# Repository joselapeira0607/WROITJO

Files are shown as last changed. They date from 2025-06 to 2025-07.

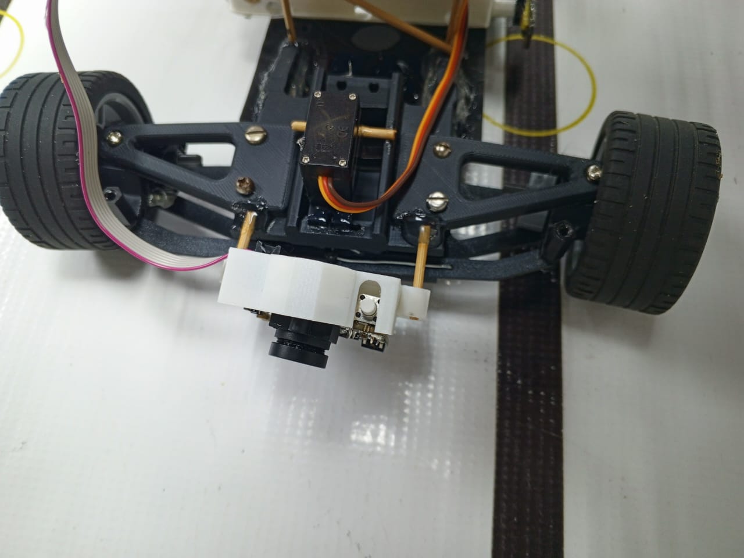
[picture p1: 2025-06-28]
v-photos/pixy-view.jpeg

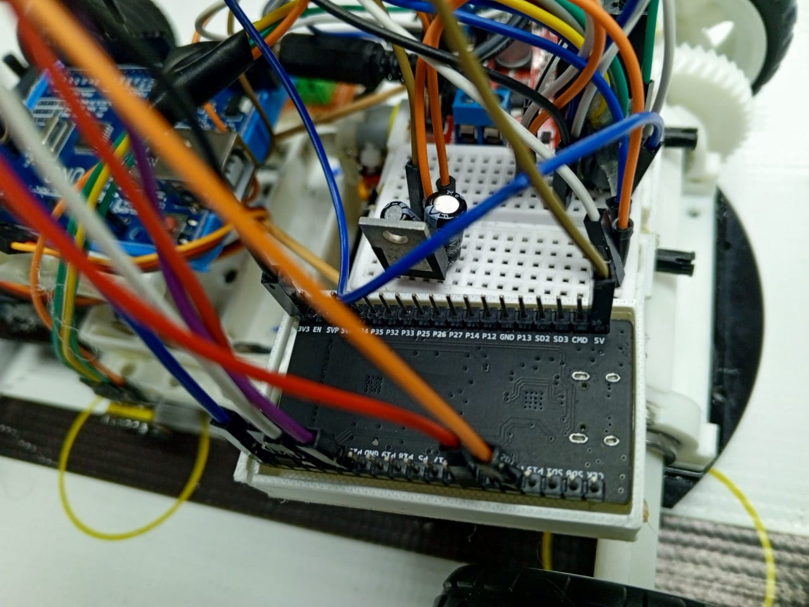
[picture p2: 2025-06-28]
v-photos/esp32-view.jpeg

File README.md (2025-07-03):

<h1 align="center"> Autonomous Robot Project for WRO - Future Engineers Category </h1>

<p align="center"> banner </p>

<br>
<h1 align="center"> World Robot Olympiad </h1>


<br>

The World Robot Olympiad (WRO) is a prestigious international robotics competition that stimulates the imagination of students worldwide. It challenges participants to demonstrate their creativity, problem-solving skills, and technical expertise in designing and programming robots for various tasks and challenges.

One of the most dynamic categories in WRO is Future Engineers. In this category, participants are tasked with developing innovative solutions to real-world problems using robotics and automation. This category serves as a breeding ground for future innovators, encouraging critical and creative thinking among students, laying the foundation for a new generation of engineers and technologists.

This year, the Future Engineers category presents an exciting challenge: creating an autonomous car. This challenge pushes participants to explore cutting-edge robotics, adding complexity and innovation to an already thrilling competition.

# 📁 Repository Structure

| Directory | Type | Description | Required |
|---|---|---|---|
| **/t-photos**  | 📸 Photos | - 1 official team photo (`team_official.jpg`)<br>- 1 informal group photo (`team_fun.jpg`) | ✅ Required |
| **/v-photos**  | 🖼️ Photos  | - 6 technical views of the robot (front, side, rear, top, bottom, detail)<br>- Minimum resolution: 1920x1080<br>- Format: `robot_[angle].jpg` | ✅ Required |
| **/video** | 🎥 Multimedia | `video.md` file containing:<br>- YouTube link (public/unlisted)<br>- Minimum 30-second demonstration<br>- Must show autonomous navigation | ✅ Required |
| **/schemes** | 📐 Diagrams | Diagrams in JPEG/PNG/PDF of:<br>- Electronic schematic<br>- Wiring connections<br>- Mechanical layout | ✅ Required |
| **/src** | 💻 Code  | Recommended structure:<br>- `/firmware` (Arduino/ESP32 code)<br>- `/vision` (image processing)<br>- `/docs` (technical manuals) | ✅ Required |
| **/models** | 🖨️ 3D/CNC | Optional files:<br>- Formats: STL, DXF, STEP<br>- Organized by component | ❌ Optional |
| **/other** | 📄 Extra | Additional documentation:<br>- Communication protocols<br>- Technical Report<br> | ❌ Optional |

## Project Objective
The objective of this project is to design, build, and program an autonomous robot using open-source hardware, sensor-based decision making, and adaptive movement algorithms. Our robot dynamically analyzes its environment through integrated processing and sensor feedback, ensuring efficient navigation while autonomously overcoming obstacles.

Main objectives:
* Strengthen problem-solving and teamwork in real-world engineering
* Implement sensor-based motion control for precise navigation
* Develop an optimized autonomous driving strategy for robotics challenges
* Contribute to open-source robotics by documenting our solution for future teams

## Components Used

Our robot is built with precision hardware to ensure stability, responsiveness, and energy optimization.

<table>
  <tr>
    <th width="150">Component</th>
    <th>Image</th>
    <th>Technical Description</th>
  </tr>
  
  <tr>
    <td><strong>Arduino Uno</strong></td>
    <td>Arduino Uno</td>
    <td>Main microcontroller managing sensor input (I2C, digital) and motion control (PWM).<br>
    <em>Specifications:</em> ATmega328P, 16MHz, 32KB flash, 14 digital I/O</td>
  </tr>

  <tr>
    <td><strong>L298N H-Bridge</strong></td>
    <td>L298N H-Bridge</td>
    <td>Dual-channel motor controller for direction and speed.<br>
    <em>Specifications:</em><br>
    • Logic voltage: 5V<br>
    • Motor voltage: +5V to +35V<br>
    • Peak current: 2A per channel<br>
    • Maximum power: 25W<br>
    • Protection: Built-in suppression diodes<br>
    <em>Arduino connection:</em><br>
    • ENA/ENB → PWM pins (speed)<br>
    • IN1/IN2 → Digital pins (direction)<br>
    • +12V → External 9V source<br>
    <em>Project use:</em> Bidirectional control of NXT motor</td>
  </tr>

<tr>
  <td><strong>DC Motor with Gearbox</strong></td>
  <td>DC Motor</td>
  <td>Compact brushed DC motor with built-in gear reduction system.<br>
  <em>Specifications:</em><br>
  • Voltage: 6–12V DC<br>
  • Gear ratio: varies by model (e.g., 48:1)<br>
  • Shaft: 6mm D-type<br>
  • Torque and speed optimized for robotic applications<br>
  <em>Wiring:</em> Two terminal leads (red: +, black: -) for connection to an L298N driver or similar H-bridge controller</td>
</tr>
  
  <tr>
    <td><strong>ESP32-WROOM-32D</strong></td>
    <td>ESP32-WROOM-32D</td>
    <td>Wi-Fi/Bluetooth MCU for IoT and embedded systems.<br>
    <em>Capabilities:</em> Dual-core 240MHz, 4MB Flash, 520KB SRAM, 802.11 b/g/n Wi-Fi, Bluetooth 4.2, low-power modes.</td>
  </tr>

  <tr>
    <td><strong>VL53L0X Sensors</strong></td>
    <td>VL53L0X</td>
    <td>Time-of-Flight (ToF) sensor for obstacle detection.<br>
    <em>Range:</em> 50-1200mm, ±3% accuracy, I2C interface</td>
  </tr>

  <tr>
    <td><strong>Breadboard</strong></td>
    <td>Breadboard</td>
    <td>Prototyping platform for quick interconnections.<br>
    <em>Configuration:</em> 830 points, power bus distribution</td>
  </tr>

  <tr>
    <td><strong>Voltage Regulators</strong></td>
    <td>LM7805 Regulator</td>
    <td>Power management system.<br>
    <em>Specifications:</em> LM7805 (5V, 1A), LM1117 (3.3V), with heat sinks</td>
  </tr>

  <tr>
    <td><strong>SG90 Servomotor</strong></td>
    <td>SG90 Servo</td>
    <td>Direction control and auxiliary mechanisms.<br>
    <em>Specifications:</em> 4.8-6V, 180° rotation, 1.8kg/cm torque</td>
  </tr>

<tr>
  <td><strong>HC-SR04 Ultrasonic Sensor</strong></td>
  <td>HC-SR04 Ultrasonic Sensor</td>
  <td>Non-contact distance measurement using ultrasonic waves.<br>
  <em>Specifications:</em> 
  <ul>
    <li>Measuring range: 2cm - 400cm</li>
    <li>Accuracy: ±3mm</li>
    <li>Operating voltage: 5V DC</li>
    <li>Current consumption: 15mA</li>
    <li>Frequency: 40kHz</li>
    <li>Detection angle: 15°</li>
  </ul>
  ESP32 connection: Trig (GPIO), Echo (GPIO), VCC (5V), GND</td>
</tr>

  <tr>
    <td><strong>Pixy2 Camera</strong></td>
    <td>Pixy2 Camera</td>
    <td>Embedded vision system for color-based object detection.<br>
    <em>Specifications:</em><br>
    • Dual-core NXP LPC4330 processor (200MHz)<br>
    • Resolution: 1296x976 (RAW), 316x208 (processed)<br>
    • Color signatures: 7 simultaneous detections<br>
    • Interfaces: SPI, I2C, UART, USB<br>
    • Power consumption: 140mA @ 5V<br>
    <em>Connection:</em> SPI (recommended) + 5V power supply<br>
    <em>Project use:</em> Target detection through color codes (signatures 3 & 4)</td>
  </tr>
</table>

## Sensor Processing and Autonomous Navigation
The VL53L0X sensor plays a crucial role in obstacle detection, allowing the robot to measure distance in real time and adjust its movement accordingly. The robot follows a sensor-driven motion algorithm, continuously refining motor speed and navigation logic.

* Obstacle detection: The distance sensor identifies objects and dynamically adjusts the robot's path
* ESP32 camera input: Processes real-time images for terrain analysis and movement decisions
* Motor control logic: The Arduino Uno manages speed control through PWM signals and servo adjustments

## Required Software and Development Tools
Programming and compilation tools:
* Arduino IDE - Used for coding, compiling and uploading firmware
* Tinkercad - Virtual electronics simulation tool for circuit prototyping

Essential libraries:
* Wire.h - Supports sensor communication and data collection
* Adafruit_VL53L0X.h - Controls distance measurement operations
* Servo.h - Manages servo motor positioning and feedback control

## Installation and Operation Instructions
How to deploy the robot firmware:
1. Download Arduino IDE and install all necessary board drivers
2. Connect Arduino Uno via USB and verify IDE recognition
3. Install all required libraries (VL53L0X, Servo, Wire, Adafruit Motor Control)
4. Compile and upload firmware, initializing sensor motion algorithms
5. Test sensor performance using Serial Monitor readings
6. Run autonomous navigation tests and fine-tune movement responses

## Diagnostics and Evaluation
Performance validation tests:
* Sensor accuracy test: Confirms obstacle detection reliability and distance precision
* Motor speed calibration: Ensures smooth motion transitions and speed adjustments
* Servo alignment: Evaluates response time and angle precision for additional motion control
* Camera-based navigation: Assesses terrain recognition and edge detection capabilities

## Competitive Strategy and Adaptability
Our robot is designed to react dynamically in competition environments, ensuring maximum precision and adaptability:

* Real-time sensor data: The robot instantly adjusts movement based on incoming distance measurements
* Vision-based edge detection: The ESP32 processes camera input to determine safe paths and avoid barriers
* Energy-efficient motion management: Reduces unnecessary movement to optimize navigation cycles
* Configurable control logic: Adjusts servo responsiveness and motor calibration as needed

## Future Development and Contribution
Our long-term vision for the project includes:

* Expanding servo control capabilities for more precise motion adjustments
* Optimizing ESP32 vision-based object tracking for advanced competition scenarios
* Developing smart battery management strategies to improve longevity and operational efficiency
* Publishing open-source documentation on sensor-based autonomous navigation solutions

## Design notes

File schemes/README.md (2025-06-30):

<h1 align="center">Schematic diagrams</h1>

Diagrama en blanco (1)

# 📁 Bill of materials

| Quantity | Component | Image | Description |
|---|---|---|---|
| 1 | Arduino Uno | Arduino | Open-source microcontroller board for prototyping. |
| 1 | Breadboard | Breadboard | Reusable platform for temporary circuits. |
| 1 | H-Bridge (L298N) | H-Bridge | Motor driver to control DC motors direction/speed. |
| 1 | DC Motor with Gearbox | DC Motor with gearbox | DC motor with a gear reduction system, ideal for increasing torque and reducing output speed. |
| 1 | Servo (S090) | Servo | Compact servo motor (0°-180° rotation). |
| 2 | VL53L0X | VL53L0X | Time-of-Flight (ToF) laser distance sensor. |
| 1 | ESP32-WROOM-32D  | ESP32 | Dual-core Wi-Fi/Bluetooth MCU for IoT. |
| 1 | Pixy2  |  | Programmable camera sensor that detects objects by color (up to 7 signatures simultaneously). Ideal for line tracking, object detection, and autonomous robot navigation. |
| 1 | HC-SR04 Ultrasonic Sensor | HC-SR04 | Affordable distance sensor that uses ultrasonic waves to detect obstacles at medium to long range. Ideal for front-facing obstacle detection. |

## ✅ Justification of Component Selection

Each component was selected based on its ability to address specific technical needs of the WRO circuit, ensuring reliable operation, integration, and performance in real-time autonomous navigation.

### 🧠 Arduino Uno
Used in the prototyping phase as a versatile and accessible microcontroller that allowed basic interfacing with sensors, actuators, and debugging tasks. It served as the foundation for early system validation before migrating to a more powerful processing unit.

### 🔌 Breadboard
Employed to expand the number of power and ground distribution points without soldering, the breadboard simplified prototyping and allowed flexible rearrangement of components across multiple testing stages.

### 🔀 L298N H-Bridge
The L298N module was critical for controlling the direction and speed of the DC motor via PWM signals. Its dual output channels made it ideal for simultaneously managing both propulsion and peripheral motion with sufficient current tolerance.

### ⚙️ DC Motor with Gearbox
Chosen for its ability to move the robot efficiently, this motor's built-in reduction gear translated high-speed rotation into greater torque, providing stability and acceleration — essential for covering the competition track rapidly and reliably.

### ↪️ SG90 Servo Motor
Responsible for adjusting the vehicle's heading, this servo was directly linked to the obstacle avoidance system. Based on input from lateral sensors and visual cues, the servo altered the front wheel angle to enable real-time evasive maneuvers.

### 👁️ VL53L0X Sensors
These Time-of-Flight sensors measured lateral distances to nearby walls or barriers. Their data fed into the control logic, triggering servo movements to prevent collisions and maintain central alignment within the circuit.

### 🎥 Pixy2 Camera
Enabled the robot to visually detect critical elements of the course such as colored columns or stoplights. It interpreted multiple color signatures in real time and passed this information to the control algorithm, allowing dynamic decisions such as obstacle avoidance or behavior modulation based on color context.

### 📡 HC-SR04
The HC-SR04 was integrated into the robotic platform as a forward-facing obstacle detection module. Its working principle—based on the reflection of ultrasonic sound waves—allowed the system to calculate the distance to frontal objects accurately within a 2–400 cm range. This made it especially useful for early detection of walls or barriers directly ahead of the robot.

### 🧠 ESP32-WROOM-32D
Deployed as the final microcontroller for its high processing speed, dual-core architecture, and robust I2C handling. It coordinated simultaneous tasks: managing sensors, computing navigation logic, and driving actuators — all essential for WRO's fast-paced circuit environment.

---

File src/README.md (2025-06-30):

# Autonomous Vehicle Control System

An Arduino-based control system for autonomous navigation using distance sensors and servo steering.

Diagrama en blanco

### Parameters
```cpp
#include <Servo.h>  // Include the Servo library to control the steering mechanism

// === PIN CONFIGURATION ===
const int motorPin1 = 3;  // Pin to control motor direction (forward)
const int motorPin2 = 6;  // Pin to control motor direction (reverse or stop)
const int servoPin   = 9; // PWM pin connected to the servo motor for steering

// === SERVO STEERING LIMITS ===
const int ANGLE_CENTER       = 90;  // Neutral angle: wheels aligned straight
const int ANGLE_MAX_RIGHT    = 120; // Max turn right angle
const int ANGLE_MAX_LEFT     = 60;  // Max turn left angle

// === SENSOR LOGIC AND SAFETY LIMITS ===
const int DIFFERENCE_THRESHOLD = 30;    // Acceptable difference (in mm) between sensors to consider straight
const int MAX_DIFFERENCE       = 160;   // Max expected measurable difference to scale the steering
const int SENSOR_TIMEOUT       = 1000;  // Stop the vehicle if no sensor data is received within this time (in ms)

// === LAPS AND TURNS CONTROL ===
const int TURNS_PER_LAP = 4;  // Number of turns that count as one lap
const int MAX_LAPS      = 3;  // Stop the vehicle after completing this many laps

// === GLOBAL VARIABLES ===
Servo myServo;                   // Servo object to control steering
String receivedData = "";        // Buffer to collect incoming serial data
bool newData         = false;    // Flag indicating whether a complete command was received
int sensorValue1     = 0;        // Latest reading from sensor 1
int sensorValue2     = 0;        // Latest reading from sensor 2
unsigned long lastSensorUpdate = 0; // Timestamp of last sensor input

// === STATE OF THE VEHICLE ===
int turnsDetected     = 0;       // Counts how many turns have been completed in the current lap
int lapsCompleted     = 0;       // Total laps completed
bool isTurning        = false;   // Tracks if the robot was turning in the last cycle
bool vehicleStopped   = false;   // True when the robot finishes its mission or hits a timeout

void setup() {
  Serial.begin(9600);  // Start serial communication to receive sensor data
  Serial.println("Arduino: System started. Waiting for sensor data...");

  pinMode(motorPin1, OUTPUT); // Motor direction pin 1
  pinMode(motorPin2, OUTPUT); // Motor direction pin 2

  myServo.attach(servoPin);   // Attach servo control to the designated pin
  centerServo();              // Initialize with centered steering
}

// === MOVEMENT CONTROL FUNCTIONS ===
void moveForward() {
  // Set motor to move forward
  digitalWrite(motorPin1, HIGH);
  digitalWrite(motorPin2, LOW);
}

void stopVehicle() {
  // Stop the motor and straighten steering
  digitalWrite(motorPin1, LOW);
  digitalWrite(motorPin2, LOW);
  centerServo();
  Serial.println("Movement: Stopped");
}

// === SERVO CONTROL ===
void centerServo() {
  // Set servo to center position
  myServo.write(ANGLE_CENTER);
}

void turnRight(int angle) {
  // Clamp angle to max range and turn servo right
  angle = constrain(angle, ANGLE_CENTER, ANGLE_MAX_RIGHT);
  myServo.write(angle);
  Serial.print("Direction: Turning right to ");
  Serial.print(angle);
  Serial.println(" degrees");
}

void turnLeft(int angle) {
  // Clamp angle to max range and turn servo left
  angle = constrain(angle, ANGLE_MAX_LEFT, ANGLE_CENTER);
  myServo.write(angle);
  Serial.print("Direction: Turning left to ");
  Serial.print(angle);
  Serial.println(" degrees");
}

// === SERIAL COMMUNICATION HANDLING ===
void recvSerialData() {
  // Reads incoming characters until newline '\n' is detected
  while (Serial.available() > 0) {
    char receivedChar = Serial.read();
    if (receivedChar == '\n') {
      newData = true; // Full command received
      break;
    }
    receivedData += receivedChar;
  }
}

void processSerialCommand() {
  // Distinguish between Sensor 1 and Sensor 2 data
  if (receivedData.startsWith("S1:")) {
    processSensorData(receivedData, sensorValue1, 1);
  } 
  else if (receivedData.startsWith("S2:")) {
    processSensorData(receivedData, sensorValue2, 2);
  }

  // Reset input buffer after processing
  receivedData = "";
  newData = false;
  lastSensorUpdate = millis();  // Update the timestamp
}

void processSensorData(String &data, int &sensorValue, int sensorNum) {
  // Extract the number from format like "S1: 123 mm"
  int mmIndex = data.indexOf(" mm");
  if (mmIndex != -1) {
    int startIndex = data.indexOf(":") + 2;
    String valueString = data.substring(startIndex, mmIndex);
    sensorValue = valueString.toInt();

    Serial.print("Sensor ");
    Serial.print(sensorNum);
    Serial.print(" updated: ");
    Serial.print(sensorValue);
    Serial.println(" mm");
  }
}

// === NAVIGATION DECISION MAKING ===
void updateSteering() {
  if (vehicleStopped) return; // If vehicle is halted, skip

  int difference = sensorValue1 - sensorValue2;

  if (abs(difference) <= DIFFERENCE_THRESHOLD) {
    // Continue straight if difference is within tolerance
    centerServo();
    handleTurnCompleted();
  } 
  else {
    // Map the difference linearly into an appropriate steering angle
    int servoAngle = map(difference, -MAX_DIFFERENCE, MAX_DIFFERENCE, 
                         ANGLE_MAX_LEFT, ANGLE_MAX_RIGHT);
    servoAngle = constrain(servoAngle, ANGLE_MAX_LEFT, ANGLE_MAX_RIGHT);

    // Turn left or right accordingly
    if (difference > 0) {
      turnRight(servoAngle);
    } else {
      turnLeft(servoAngle);
    }

    isTurning = true; // Flag that we're mid-turn
  }
}

void handleTurnCompleted() {
  // Detect change from turning to straight
  if (isTurning) {
    turnsDetected++;
    Serial.print("Turn completed. Total: ");
    Serial.println(turnsDetected);

    // If number of turns equals one full lap
    if (turnsDetected >= TURNS_PER_LAP) {
      lapsCompleted++;
      Serial.print("Lap completed: ");
      Serial.println(lapsCompleted);

      turnsDetected = 0; // Reset counter for the next lap

      if (lapsCompleted >= MAX_LAPS) {
        // Mission success! Stop everything
        vehicleStopped = true;
        stopVehicle();
        Serial.println("Mission complete: 3 laps finished");
      }
    }

    isTurning = false; // Reset turn state
  }
}

void checkSensorTimeout() {
  // If too much time passed without sensor input, stop for safety
  if (millis() - lastSensorUpdate > SENSOR_TIMEOUT) {
    Serial.println("WARNING: Sensor timeout. Stopping vehicle...");
    stopVehicle();
    vehicleStopped = true;
  }
}

// === MAIN LOOP ===
void loop() {
  if (vehicleStopped) return; // Skip logic if mission is already done

  recvSerialData();       // Check for new sensor data
  if (newData) {
    processSerialCommand();
  }

  // Run only if vehicle is allowed to move
  if (!vehicleStopped) {
    moveForward();        // Activate motors
    updateSteering();     // Adjust direction based on sensors
    checkSensorTimeout(); // Safety mechanism
  }
}

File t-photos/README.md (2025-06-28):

## Who Are We?

We are JO SLD, a dynamic and passionate team proudly born from the classrooms of Jesús Obrero Technical Institute, an institution known for nurturing skilled professionals grounded in discipline, innovation, and teamwork. Our name carries the initials of our members—José, Keiner, and Mauricio—and represents our shared commitment to excellence in robotics and technology.

Our team is made up of:

- José Lapeira – High school graduate in Computer Science. A coding strategist with a keen eye for algorithmic logic and system structure. His precision is reflected in every line of code.

- Keiner Durán – Also a Computer Science graduate, he’s the integration specialist of the team. Always seeking ways to improve performance and synchronization between hardware and software components.

- Mauricio Sánchez – Electronics high school graduate and IT college technician (TSU). The electronics mastermind who balances circuit design with technical robustness and reliability.

At Jesús Obrero, we didn’t just learn theory—we embraced a way of thinking: with purpose, detail, and unity. Our mission is to represent our school, our community, and our country through projects that combine technology, creativity, and social impact.

Our motto: “From technique to impact” — because each prototype we build is our way of contributing to a smarter, better future.

Official:
official

Funny photo:
funny

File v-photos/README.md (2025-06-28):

Vehicle's photos
====

## Front position
front-view

## Left position
right-view

## Right position
left-view

## Back position
back-view

## Top position
top-view

## Bottom position
bottom-view

## Wheels
wheels-view

## Arduino
arduino-view

## Batteries
batteries

## Esp32
esp32-view

## Pixy2
pixy-view

## H Bridge
H bridge-view

## Motor 
motor-view

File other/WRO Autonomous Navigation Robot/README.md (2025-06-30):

<h1 align="center">Technical Report</h1>
<h2 align="center">Development of an Autonomous Robot for the World Robot Olympiad (WRO)</h2>

<p align="center"><i>Complete documentation of the design, optimization, and results of an autonomous mobile robot prepared to navigate obstacle-filled closed circuits.</i></p>

---

## 🧭 Introduction

This document provides a detailed description of the design, assembly, optimization, and validation process of an autonomous robot created to compete in the World Robot Olympiad (WRO). The primary technical objective was to enable the robot to complete three laps within a closed circuit while precisely avoiding walls and intermediate obstacles.

Throughout the process, we addressed challenges in three fundamental areas: mechanics, electronics, and intelligent control. Technical iterations allowed us to refine both the hardware and navigation algorithm, resulting in a robust and reliable system.

> 📷 460205220-4385875f-8fb5-4cfd-8109-ed76797ce5a7

---

## 🧪 Initial Phase: LEGO Prototyping (March)

The initial stage focused on building a functional prototype using LEGO Mindstorms components, given their modular versatility and ease of testing.

### Mechanical Design

We developed a basic chassis with LEGO components, which incorporated:
- A differential steering system
- Front wheels connected to a 3D-printed toothed beam actuated by a servo motor
- Rear wheels with traction provided by an NXT motor

### Electronic Circuit

The initial control and detection system consisted of:
- **Microcontroller:** Arduino UNO  
- **Motor control:** L298N H-bridge  
- **Sensing:** Two HC-SR04 ultrasonic sensors positioned front and side  
- **Power:** Three 4V rechargeable batteries connected in series (12V total) distributed via breadboard  

> 📷 

### Identified Technical Issues

During initial testing, we identified significant limitations:
- High sensitivity to ultrasonic noise in HC-SR04 sensors, causing false detections
- Limited precision in tight turns due to structural flexibility of the LEGO differential system
- Torque loss and vibrations from NXT motor overheating at high speeds

---

## 🔧 Optimization: Sensors and Controller

Based on the identified issues, we restructured the sensing and control system.

### Migration to VL53L0X Sensors

The ultrasonic system was replaced with VL53L0X Time-of-Flight sensors, which offered:
- Millimeter resolution with high stability
- Immunity to environmental acoustic interference
- Adjustable detection range up to 2 meters

**Resulting challenges:**
- Sensor performance was affected by excessive lighting
- I2C protocol readings required higher processing speed

### ESP32 Integration

To improve parallel reading and processing capability, we integrated an ESP32 that provided:
- Dual-core processing for multitasking (parallel sensor reading and motor control)
- More efficient I2C communication without bus congestion

---

## ⚙️ Mechanical Redesign: DKS-Basic Chassis

### LEGO Chassis Limitations
- Low structural rigidity under dynamic loads
- Play in mobile connections
- Excessive weight, reducing agility and autonomy

### DKS-Basic Advantages

We transitioned to a professional metal chassis (DKS-Basic) that offered:
- Greater resistance thanks to anodized aluminum
- Ball bearing system reducing friction
- More compact geometry optimizing tight turns
- Compatibility with commercial DC motors

### Traction System Upgrade
- Replaced NXT motor with gear-reduced DC motor
- Improved torque and speed control with PWM signal
- Custom CAD-designed 3D-printed wheels adapted to the new chassis bearings

> 📷 left-view

---

## 🧠 Final Sensing and Control System

### Sensor Configuration

The final version incorporated a hybrid sensor architecture:
- 1x HC-SR04 (front position) for long-range obstacle detection
- 2x VL53L0X (side) for curve navigation and precise avoidance

### Avoidance Algorithm

We implemented deterministic logic firmware using a finite state machine (FSM) defining three operation modes:
1. **Free movement:** no detected obstacles
2. **Lateral turn:** partial wall presence
3. **Braking and reverse:** critical front wall detection

Readings were filtered using a median algorithm to eliminate anomalous values.

---

## 📈 Evaluation and Results

### Performance Metrics

| Parameter | Achieved Value  |
|---|---|
| Maximum speed | 1.2 m/s |
| Average lap time | 15 seconds |
| Turning precision | ±2 cm |
| Detection accuracy | 98% |

### Lessons Learned
- Sensor redundancy significantly improves reliability
- A professional chassis greatly contributes to dynamic stability
- The ESP32 proves highly suitable for real-time navigation systems requiring simultaneous multitasking

---

## 🏁 Conclusion

The developed robotic system not only met the WRO competition requirements but exceeded precision and stability expectations. The implementation of hybrid sensors, a high-performance controller like the ESP32, and a professional mechanical chassis were determining factors in the project's success.

Beyond its competition participation, this robot represents a solid technical foundation for developing future autonomous navigation platforms in dynamic environments.

---

## 👥 Development Team

**Author:** JO SLD  
**Year:** 2025  
**Collaborators:** *Keiner Duran, Jose Lapeira, Mauricio Sanchez*

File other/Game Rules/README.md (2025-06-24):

Spanish (Español):
[REGLAS - FUTUROS INGENIEROS WRO VENEZUELA 2025.pdf](https://github.com/user-attachments/files/20887060/REGLAS.-.FUTUROS.INGENIEROS.WRO.VENEZUELA.2025.pdf)

English (Inglés):
[WRO-2025-Future-Engineers-Self-Driving-Cars-General-Rules.pdf](https://github.com/user-attachments/files/20887080/WRO-2025-Future-Engineers-Self-Driving-Cars-General-Rules.pdf)

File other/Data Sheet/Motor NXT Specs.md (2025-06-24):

# 🏗️ LEGO NXT Motor + H-Bridge Adapter Setup  

<div align="center">
  NXT Motor with H-Bridge Adapter
  <br>  
  <em>LEGO NXT Motor modified with custom RJ12-to-Dupont adapter for H-Bridge control</em>
</div>

---

## 🔧 **Technical Specifications**  

| **Parameter** | **Details** |
|---|---|
| **Motor Type** | DC Brushed + Optical Encoder |
| **Operating Voltage** | 9V DC (7-12V range) |
| **No-Load Speed** | 170-180 RPM |
| **Stall Torque** | 15 N·cm |
| **Encoder Resolution** | 3 pulses per revolution (±1° precision) |
| **Connection** | Custom RJ12 → Dupont adapter to H-Bridge |

---

## ⚡ **H-Bridge Wiring Diagram**  
```plaintext
NXT Motor Cable       H-Bridge (L298N)  
───────────────────────────────────────  
Red (+)    →→→  OUTPUT 1  
Black (-)  →→→  OUTPUT 2  
White      →→→  (Encoder - Not Connected)  
Yellow     →→→  (Encoder - Not Connected)  
```

**Key Connection Notes:**  
- 🟢 **Power**: Use separate 9V supply for motors (not Arduino 5V).  
- 🔄 **Direction Control**: Swap `OUTPUT 1`/`OUTPUT 2` to reverse rotation.  
- 🎛️ **Speed Control**: Connect `ENA` (PWM) to Arduino (e.g., Pin 9).

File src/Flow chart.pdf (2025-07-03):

Inicia comunicación serial a 9600 baudios

### motorPin1= 3

### ANGLE_CENTER = 90°

Dirección
adelante
motorPin2 = 6 | Dirección reversa/parada
servoPin = 9 | Conecta servo al pin PWM

Dirección recta del servo

¿El

### vehículo está detenido?

No

Activa los pines del motor para que el vehículo avance hacia adelante.

Calcula la diferencia entre la distancia leída por el sensor 1y el sensor 2:
di f f er ence = sensor Val ue1 - sensor Val ue2
ANGLE_MAX_RIGHT = 120° | Dirección derecha del servo
ANGLE_MAX_LEFT = 60° | Dirección izquierda del servo
sensorValue1= 0 | Primer sensor
sensorValue2 = 0 | Segundo sensor
DIFFERENCE_THRESHOLD = 30 | Diferencia límite
MAX_DIFFERENCE = 160 | Diferencia máxima

### ¿La diferencia es menor o igual al umbral?

Sí

La posición del servo entra a 90°

### ¿Está en línea recta?

isTurning = false | Realiza un seguimiento si el robot estaba girando en el último ciclo

Sí

### Aumenta el contador de giros:

t ur nsDet ect ed++

turnsDetected = 0 | Cuenta cuantos giros se han completado en la vuelta actual

### ¿Completó los 4 giros?

TURNS_PER_LAP = 4 | Número de giros que cuentan como una vuelta

Sí

### Suma una vuelta más:

l apsCompl et ed++

lapsCompleted = 0 | Total de vueltas completas

### Reiniciar el contador para la siguiente vuelta:

t ur nsDet ect ed = 0

### ¿Realizó las tres vueltas?

### El vehículo se detiene totalmente:

vehi cl eSt opped = t r ue

Sí

### vehicleStopped = false

Verdadero cuando el robot termina su misión o alcanza un tiempo de espera

Se detienen los motores y endereca la dirección del servo a 90°

No

Mapea esa diferencia a un ángulo entre 60° (giro izquierda máximo) y 120° (giro derecha máximo), usando la función: map( di f f er ence, - 160, 160, 60, 120) ;

Luego limita el ángulo para que no exceda esos valores con constrain().

Sí | ¿La diferencia es mayor a cero?

Sujeta el ángulo del servo al rango máximo y gira el
servo a la derecha: mySer vo. wr i t e( 120)

No

Sujeta el ángulo del servo al rango máximo y gira el servo a la
izquierda: mySer vo. wr i t e( 60)

Marca que el robot está en pleno giro:
i sTur ni ng = t r ue

### ¿Ha pasado más de 1000 milisegundos sin recibir datos nuevos?

Sí

Se detienen los motores y endereca la dirección del servo a 90°

### El vehículo se detiene totalmente:

vehi cl eSt opped = t r ue

SENSOR_TIMEOUT = 1000 | Detenga el vehículo si no se reciben datos del sensor dentro de este tiempo (en ms)

# Fin

# Inicio

Si

No

No

No

No

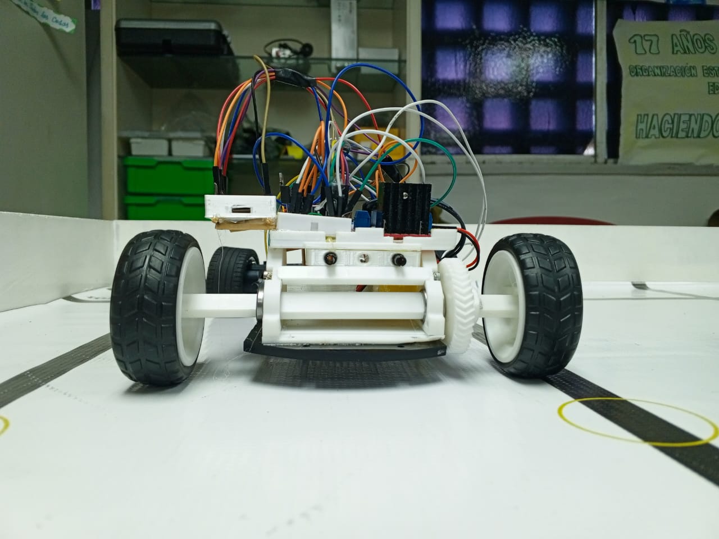
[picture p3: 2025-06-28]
v-photos/back-view.jpeg

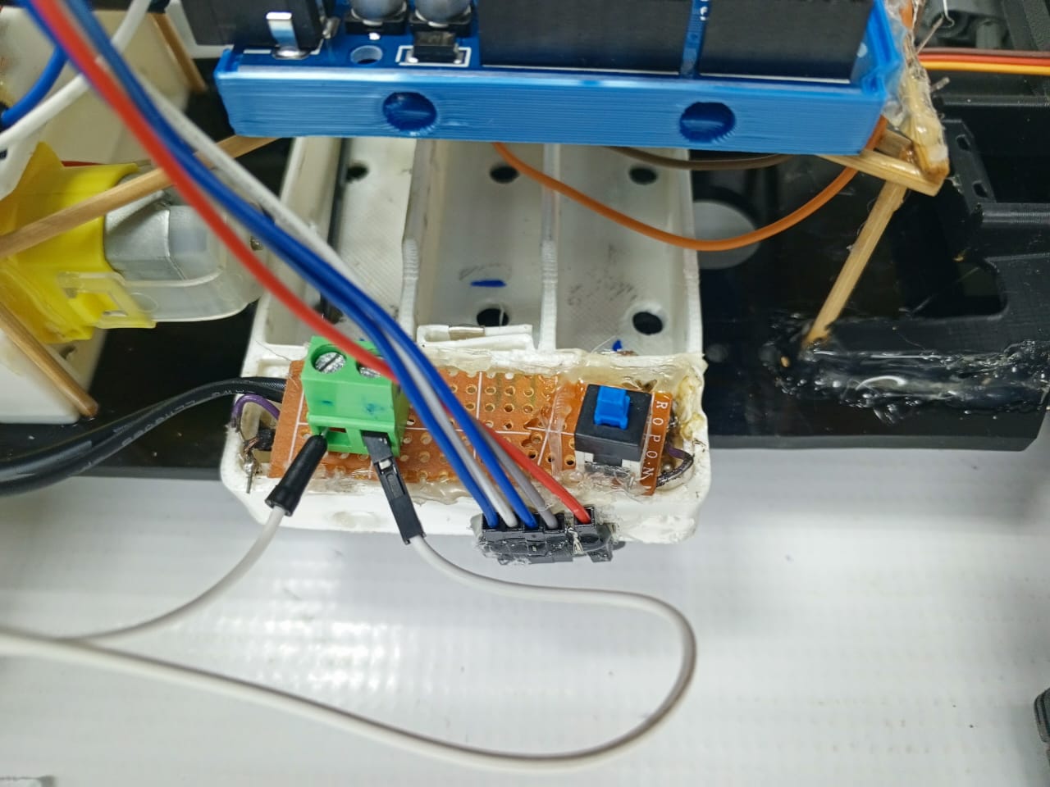
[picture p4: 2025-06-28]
v-photos/batteries.jpeg

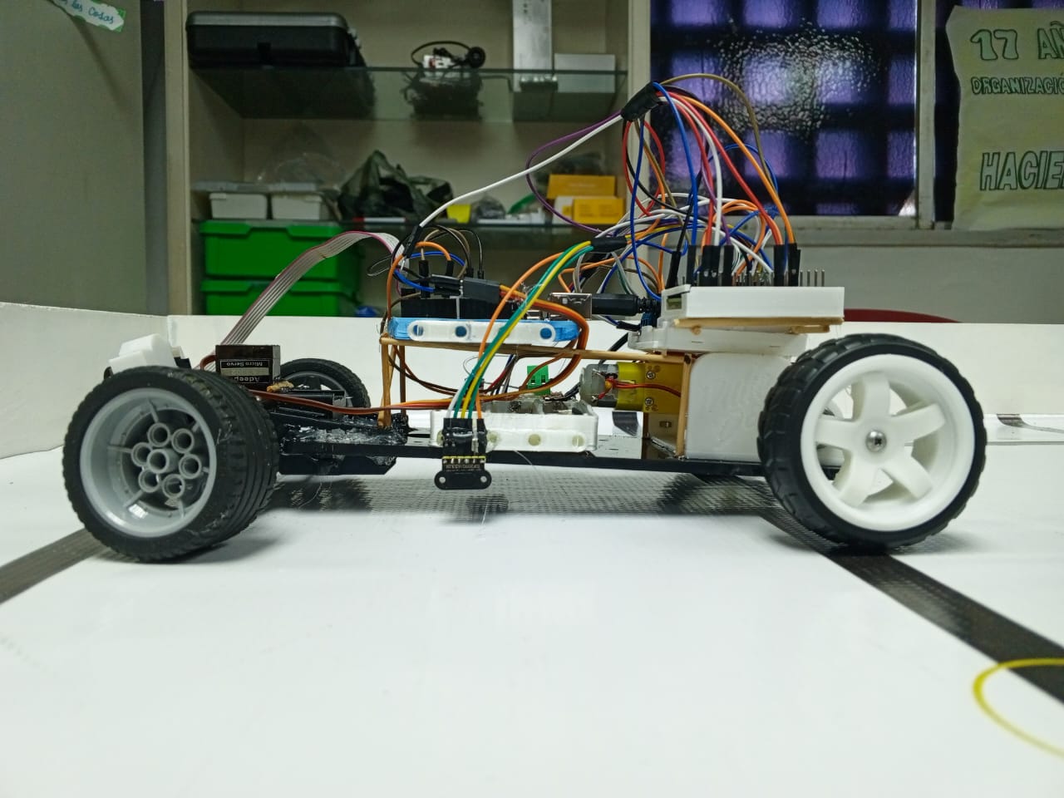
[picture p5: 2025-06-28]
v-photos/right-view.jpeg

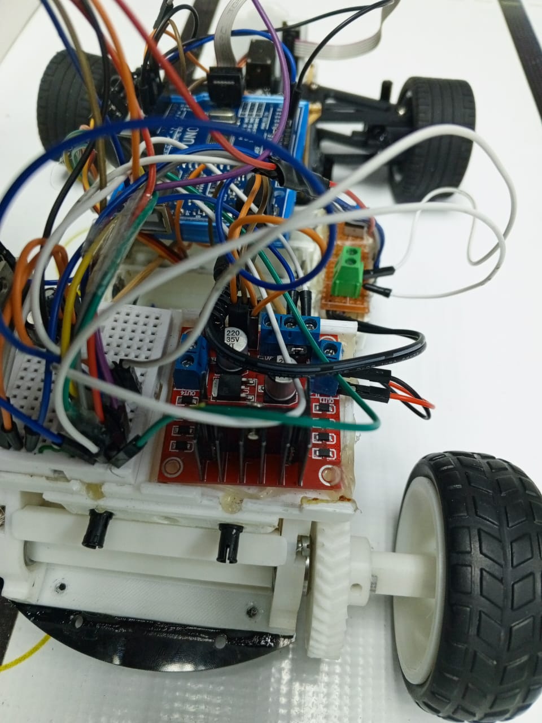
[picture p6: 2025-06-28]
v-photos/H bridge-view.jpeg

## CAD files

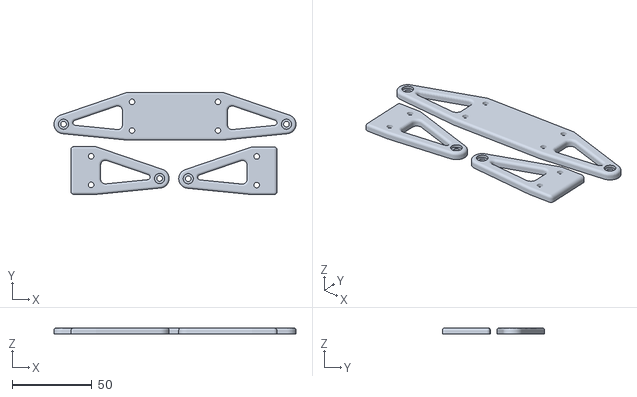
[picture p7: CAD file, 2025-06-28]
models/Front Absorbers.stl
152.0 x 64.2 x 4.00

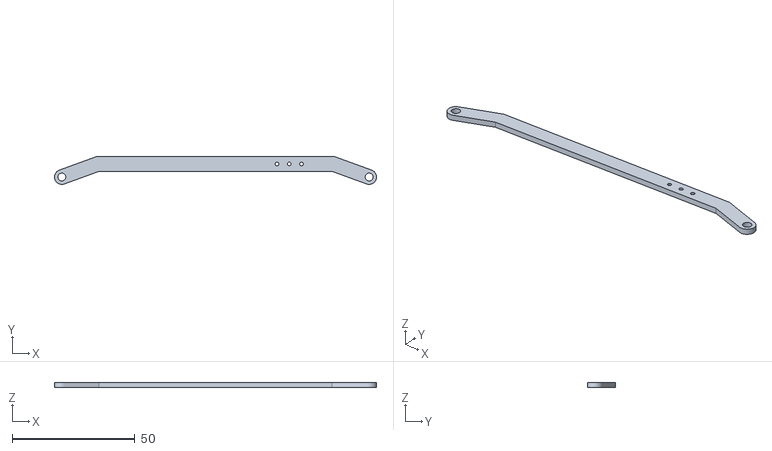
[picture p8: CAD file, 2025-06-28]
models/Steering.stl
131.0 x 11.3 x 2.00

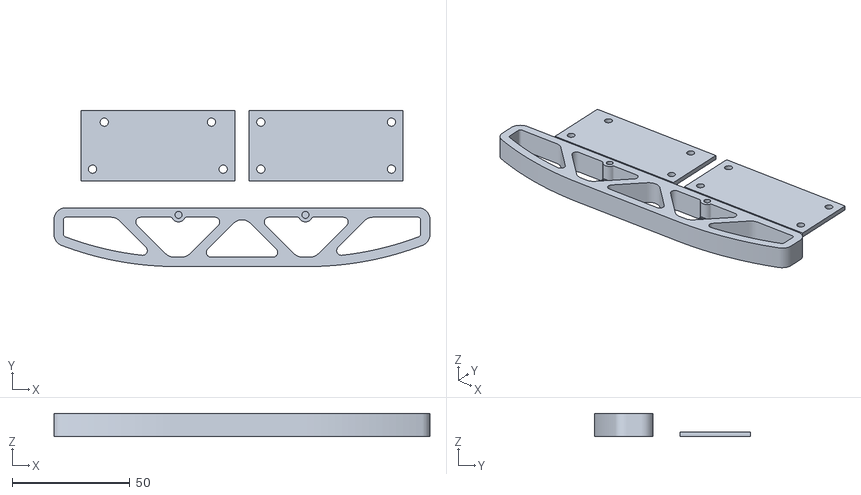
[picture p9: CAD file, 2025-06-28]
models/Rear Absorbers Bumper.stl
160.0 x 66.5 x 9.90

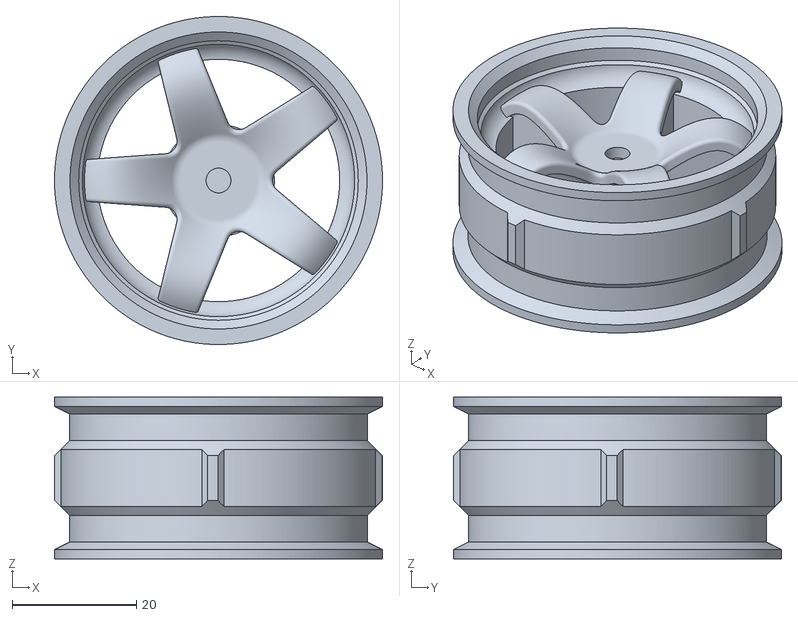
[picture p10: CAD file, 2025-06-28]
models/Wheel with supports.stl
52.8 x 52.8 x 26.0

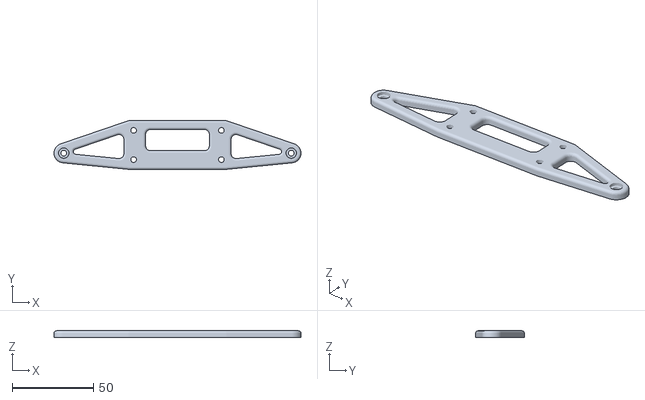
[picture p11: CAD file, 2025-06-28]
models/Front Bars Upper.stl
152.0 x 30.0 x 4.00

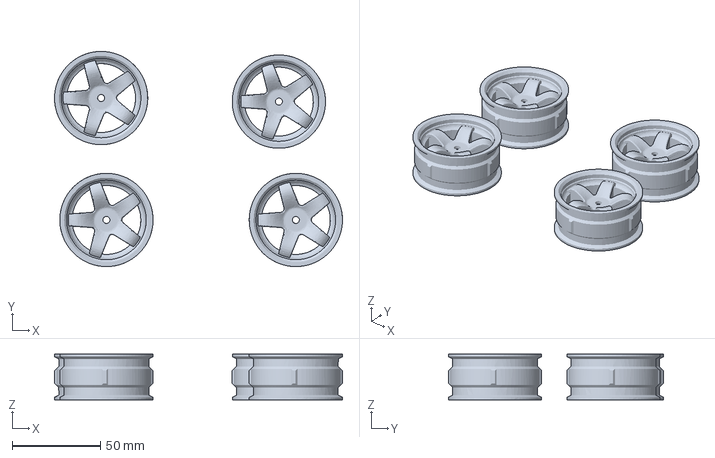
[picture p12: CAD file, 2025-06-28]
models/Wheels.3mf
163.0 x 121.8 x 26.0 mm

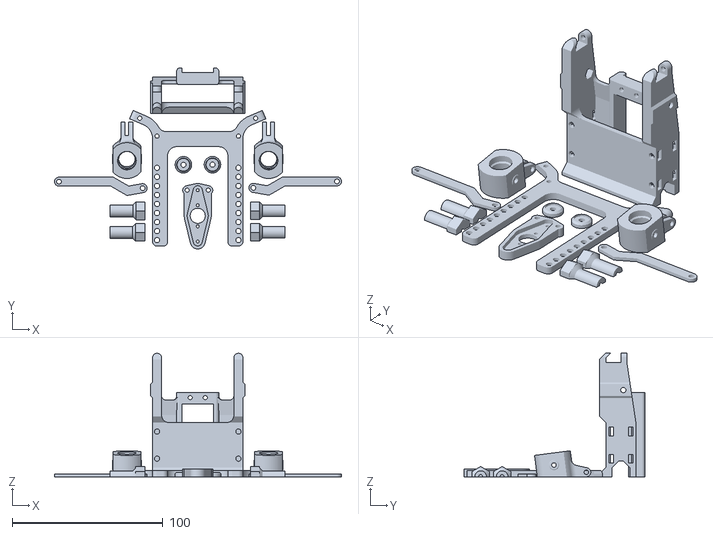
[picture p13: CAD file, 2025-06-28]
models/Stearing.stl
190.5 x 120.1 x 82.0

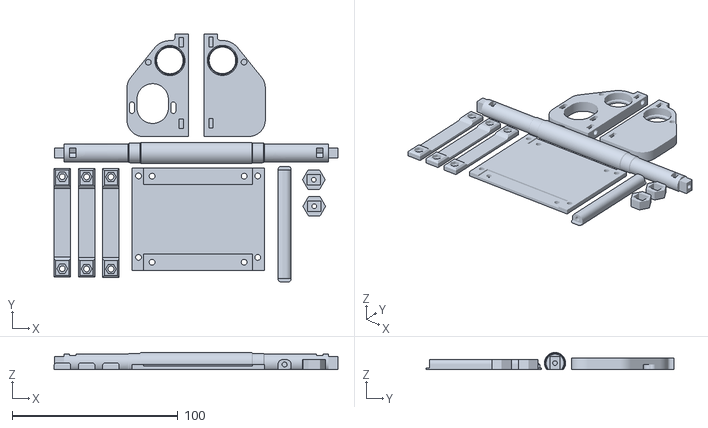
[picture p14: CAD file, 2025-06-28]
models/Rear Axis.stl
171.6 x 150.0 x 10.3

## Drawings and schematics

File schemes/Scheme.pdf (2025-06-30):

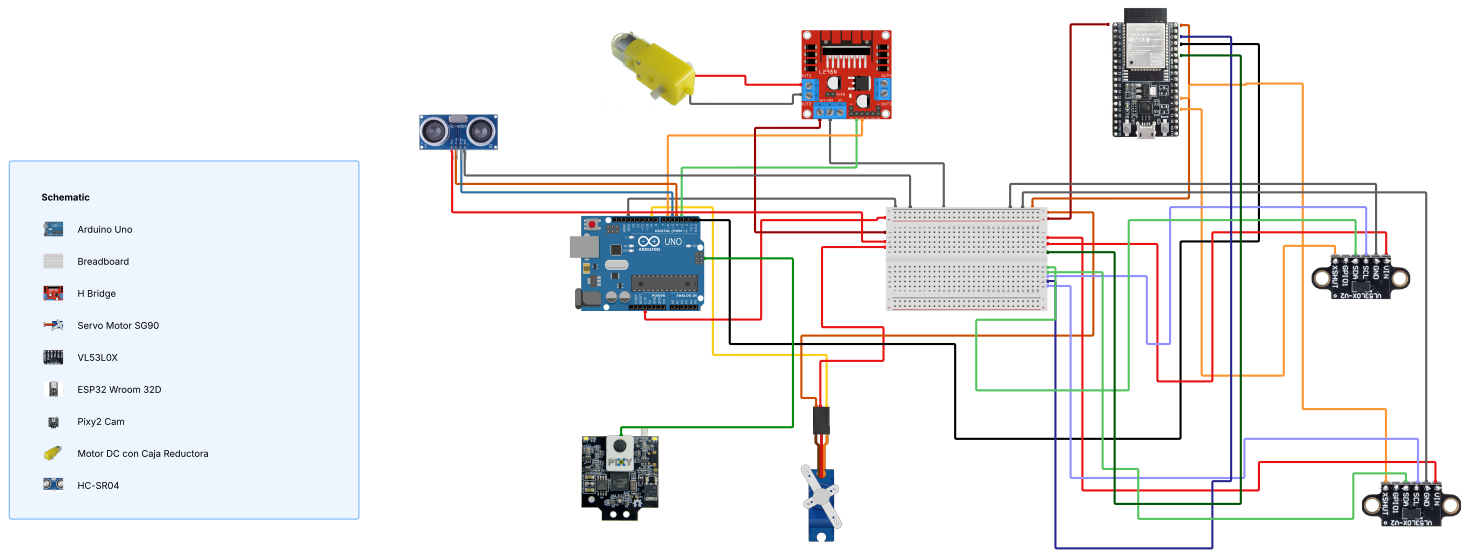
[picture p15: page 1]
Schematic; Arduino Uno; Breadboard; H Bridge; Servo Motor SG90; ESP32 Wroom 32D; Pixy2 Cam

Motor DC con Caja Reductora

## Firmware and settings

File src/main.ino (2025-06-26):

#include <Servo.h>

// --- Configuración de pines ---
const int motorPin1 = 3; // Control dirección motor (HIGH/LOW)
const int motorPin2 = 6; // Control dirección motor (HIGH/LOW)
const int servoPin = 9; // Pin para control del servo

// --- Parámetros del servo ---
const int ANGULO_CENTRO = 90;
const int ANGULO_MAX_DERECHA = 120;
const int ANGULO_MAX_IZQUIERDA = 60;

// --- Umbrales y constantes ---
const int UMBRAL_DIFERENCIA = 30; // mm para considerar recto
const int MAX_DIFERENCIA = 160; // mm diferencia máxima esperada
const int TIMEOUT_SENSORES = 1000; // ms sin datos antes de detenerse

// --- Control de vueltas ---
const int GIROS_POR_VUELTA = 4;
const int MAX_VUELTAS = 3;

// --- Variables del sistema ---
Servo myServo;
String receivedData = "";
bool newData = false;
int valorSensor1 = 0;
int valorSensor2 = 0;
unsigned long lastSensorUpdate = 0;

// --- Estado del vehículo ---
int girosDetectados = 0;
int vueltasCompletadas = 0;
bool estaGirando = false;
bool vehiculoDetenido = false;

void setup() {
  Serial.begin(9600);
  Serial.println("Arduino: Sistema iniciado. Esperando datos de sensores...");

  // Configuración pines motor (solo ON/OFF)
  pinMode(motorPin1, OUTPUT);
  pinMode(motorPin2, OUTPUT);
  
  // Configuración servo
  myServo.attach(servoPin);
  centrarServo();
}

// ================= FUNCIONES DE CONTROL =================

// --- Control de movimiento (ON/OFF) ---
void avanzar() {
  digitalWrite(motorPin1, HIGH);
  digitalWrite(motorPin2, LOW);
}

void detener() {
  digitalWrite(motorPin1, LOW);
  digitalWrite(motorPin2, LOW);
  centrarServo();
  Serial.println("Movimiento: Detenido");
}

// --- Control de dirección ---
void centrarServo() {
  myServo.write(ANGULO_CENTRO);
}

void girarDerecha(int angulo) {
  angulo = constrain(angulo, ANGULO_CENTRO, ANGULO_MAX_DERECHA);
  myServo.write(angulo);
  Serial.print("Dirección: Girando derecha a ");
  Serial.print(angulo);
  Serial.println(" grados");
}

void girarIzquierda(int angulo) {
  angulo = constrain(angulo, ANGULO_MAX_IZQUIERDA, ANGULO_CENTRO);
  myServo.write(angulo);
  Serial.print("Dirección: Girando izquierda a ");
  Serial.print(angulo);
  Serial.println(" grados");
}

// --- Comunicación Serial ---
void recvSerialData() {
  while (Serial.available() > 0) {
    char receivedChar = Serial.read();
    
    if (receivedChar == '\n') {
      newData = true;
      break;
    }
    
    receivedData += receivedChar;
  }
}

void processSerialCommand() {
  if (receivedData.startsWith("S1:")) {
    procesarDatosSensor(receivedData, valorSensor1, 1);
  } 
  else if (receivedData.startsWith("S2:")) {
    procesarDatosSensor(receivedData, valorSensor2, 2);
  }
  
  receivedData = "";
  newData = false;
  lastSensorUpdate = millis();
}

void procesarDatosSensor(String &data, int &valorSensor, int numSensor) {
  int mmIndex = data.indexOf(" mm");
  if (mmIndex != -1) {
    int startIndex = data.indexOf(":") + 2;
    String valueString = data.substring(startIndex, mmIndex);
    valorSensor = valueString.toInt();
    
    Serial.print("Sensor ");
    Serial.print(numSensor);
    Serial.print(" actualizado: ");
    Serial.print(valorSensor);
    Serial.println(" mm");
  }
}

// --- Lógica de navegación ---
void actualizarDireccion() {
  if (vehiculoDetenido) return;

  int diferencia = valorSensor1 - valorSensor2;

  if (abs(diferencia) <= UMBRAL_DIFERENCIA) {
    centrarServo();
    manejarGiroCompletado();
  } 
  else {
    int anguloServo = map(diferencia, -MAX_DIFERENCIA, MAX_DIFERENCIA, 
                         ANGULO_MAX_IZQUIERDA, ANGULO_MAX_DERECHA);
    anguloServo = constrain(anguloServo, ANGULO_MAX_IZQUIERDA, ANGULO_MAX_DERECHA);
    
    if (diferencia > 0) {
      girarDerecha(anguloServo);
    } else {
      girarIzquierda(anguloServo);
    }
    
    estaGirando = true;
  }
}

void manejarGiroCompletado() {
  if (estaGirando) {
    girosDetectados++;
    Serial.print("Giro completado. Total: ");
    Serial.println(girosDetectados);
    
    if (girosDetectados >= GIROS_POR_VUELTA) {
      vueltasCompletadas++;
      Serial.print("Vuelta completada: ");
      Serial.println(vueltasCompletadas);
      
      girosDetectados = 0;
      if (vueltasCompletadas >= MAX_VUELTAS) {
        vehiculoDetenido = true;
        detener();
        Serial.println("Misión completada: 3 vueltas");
      }
    }
    
    estaGirando = false;
  }
}

void verificarTimeoutSensores() {
  if (millis() - lastSensorUpdate > TIMEOUT_SENSORES) {
    Serial.println("ALERTA: Timeout en sensores. Deteniendo...");
    detener();
    vehiculoDetenido = true;
  }
}

// --- Loop principal ---
void loop() {
  if (vehiculoDetenido) return;

  recvSerialData();
  if (newData) processSerialCommand();

  if (!vehiculoDetenido) {
    avanzar();
    actualizarDireccion();
    verificarTimeoutSensores();
  }
}

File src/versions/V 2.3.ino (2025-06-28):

#include <Pixy2.h>
#include <Servo.h>
#include <SPI.h>

// --- Configuración de pines ---
const int motorPin1 = 3;       // Control motor
const int motorPin2 = 6;       // Control motor
const int servoPin = 9;        // Servo dirección
const int trigPin = 4;         // Ultrasónico Trigger
const int echoPin = 5;         // Ultrasónico Echo

// --- Sensores de color (Pixy2) ---
Pixy2 pixy;

// --- Parámetros del servo ---
const int ANGULO_CENTRO = 90;
const int ANGULO_MAX_DERECHA = 120;
const int ANGULO_MAX_IZQUIERDA = 60;

// --- Umbrales y constantes ---
const int UMBRAL_DIFERENCIA = 30;     // mm para considerar recto
const int MAX_DIFERENCIA = 160;       // mm diferencia máxima
const int DISTANCIA_OBSTACULO = 20;   // cm para activar giro
const int TIMEOUT_SENSORES = 1000;    // ms sin datos antes de detenerse

// --- Control de vueltas ---
const int GIROS_POR_VUELTA = 4;
const int MAX_VUELTAS = 3;

// --- Firmas de color Pixy2 ---
#define SIG_VERDE 1
#define SIG_ROJO 2
const int UMBRAL_AREA = 3000;         // Tamaño mínimo para considerar objeto

// --- Variables del sistema ---
Servo myServo;
int valorSensor1 = 0;
int valorSensor2 = 0;
unsigned long lastSensorUpdate = 0;
float distanciaFrontal = 0;

// --- Estado del vehículo ---
int girosDetectados = 0;
int vueltasCompletadas = 0;
bool estaGirando = false;
bool vehiculoDetenido = false;
bool paredCercana = false;

// --- Estados de navegación ---
enum ModoNavegacion {MODO_VUELTAS, MODO_ESQUIVA};
ModoNavegacion modoActual = MODO_VUELTAS;

void setup() {
  Serial.begin(9600);
  Serial.println("Iniciando sistema combinado...");

  // Inicializar Pixy2
  pixy.init();
  Serial.println("Pixy2 inicializado");

  // Configuración pines motor
  pinMode(motorPin1, OUTPUT);
  pinMode(motorPin2, OUTPUT);
  
  // Configuración servo
  myServo.attach(servoPin);
  centrarServo();

  // Configuración sensor ultrasónico
  pinMode(trigPin, OUTPUT);
  pinMode(echoPin, INPUT);
}

// ================= FUNCIONES PRINCIPALES =================

void avanzar() {
  digitalWrite(motorPin1, HIGH);
  digitalWrite(motorPin2, LOW);
}

void detener() {
  digitalWrite(motorPin1, LOW);
  digitalWrite(motorPin2, LOW);
  centrarServo();
}

float medirDistancia() {
  digitalWrite(trigPin, LOW);
  delayMicroseconds(2);
  digitalWrite(trigPin, HIGH);
  delayMicroseconds(10);
  digitalWrite(trigPin, LOW);
  long duracion = pulseIn(echoPin, HIGH);
  return duracion * 0.034 / 2;
}

void procesarColor() {
  pixy.ccc.getBlocks();
  
  if (pixy.ccc.numBlocks) {
    for (int i = 0; i < pixy.ccc.numBlocks; i++) {
      int signature = pixy.ccc.blocks[i].m_signature;
      int area = pixy.ccc.blocks[i].m_width * pixy.ccc.blocks[i].m_height;
      
      if (area > UMBRAL_AREA) {
        Serial.print("Objeto detectado: ");
        Serial.print(signature == SIG_VERDE ? "VERDE" : "ROJO");
        Serial.print(" Area: ");
        Serial.println(area);

        // Cambiar a modo esquiva si detecta objeto importante
        if (signature == SIG_VERDE || signature == SIG_ROJO) {
          modoActual = MODO_ESQUIVA;
          if (signature == SIG_VERDE) {
            girarIzquierda(ANGULO_MAX_IZQUIERDA);
          } else {
            girarDerecha(ANGULO_MAX_DERECHA);
          }
          delay(800); // Tiempo de giro
          centrarServo();
          modoActual = MODO_VUELTAS; // Volver al modo normal
          return;
        }
      }
    }
  }
}

void actualizarDireccion() {
  distanciaFrontal = medirDistancia();
  procesarColor(); // Verificar objetos de color primero

  if (modoActual == MODO_ESQUIVA) return;

  paredCercana = (distanciaFrontal <= DISTANCIA_OBSTACULO);

  if (!paredCercana) {
    centrarServo();
    manejarGiroCompletado();
    return;
  }

  // Lógica de giro basada en sensores laterales
  int diferencia = valorSensor1 - valorSensor2;

  if (abs(diferencia) > UMBRAL_DIFERENCIA) {
    int anguloServo = map(diferencia, -MAX_DIFERENCIA, MAX_DIFERENCIA, 
                         ANGULO_MAX_IZQUIERDA, ANGULO_MAX_DERECHA);
    anguloServo = constrain(anguloServo, ANGULO_MAX_IZQUIERDA, ANGULO_MAX_DERECHA);
    
    myServo.write(anguloServo);
    estaGirando = true;
  } else {
    manejarGiroCompletado();
  }
}

void manejarGiroCompletado() {
  if (estaGirando) {
    girosDetectados++;
    Serial.print("Giro completado. Total: ");
    Serial.println(girosDetectados);
    
    if (girosDetectados >= GIROS_POR_VUELTA) {
      vueltasCompletadas++;
      Serial.print("Vuelta completada: ");
      Serial.println(vueltasCompletadas);
      
      girosDetectados = 0;
      if (vueltasCompletadas >= MAX_VUELTAS) {
        vehiculoDetenido = true;
        detener();
        Serial.println("Misión completada: 3 vueltas");
      }
    }
    estaGirando = false;
  }
  centrarServo();
}

// ================= FUNCIONES AUXILIARES =================

void girarDerecha(int angulo) {
  angulo = constrain(angulo, ANGULO_CENTRO, ANGULO_MAX_DERECHA);
  myServo.write(angulo);
  Serial.print("Girando derecha: ");
  Serial.println(angulo);
}

void girarIzquierda(int angulo) {
  angulo = constrain(angulo, ANGULO_MAX_IZQUIERDA, ANGULO_CENTRO);
  myServo.write(angulo);
  Serial.print("Girando izquierda: ");
  Serial.println(angulo);
}

void centrarServo() {
  myServo.write(ANGULO_CENTRO);
}

void loop() {
  if (vehiculoDetenido) return;

  // Simular lectura de sensores laterales (reemplazar con tu código real)
  valorSensor1 = random(100, 200);
  valorSensor2 = random(100, 200);
  lastSensorUpdate = millis();

  if (!vehiculoDetenido) {
    avanzar();
    actualizarDireccion();
  }

  delay(50);
}

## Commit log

2025-06-10 Create esp32
2025-06-24 Update and rename README.md to Motor NXT Specs.md
2025-07-03 Rename Diagrama de flujo.pdf to Flow chart.pdf
